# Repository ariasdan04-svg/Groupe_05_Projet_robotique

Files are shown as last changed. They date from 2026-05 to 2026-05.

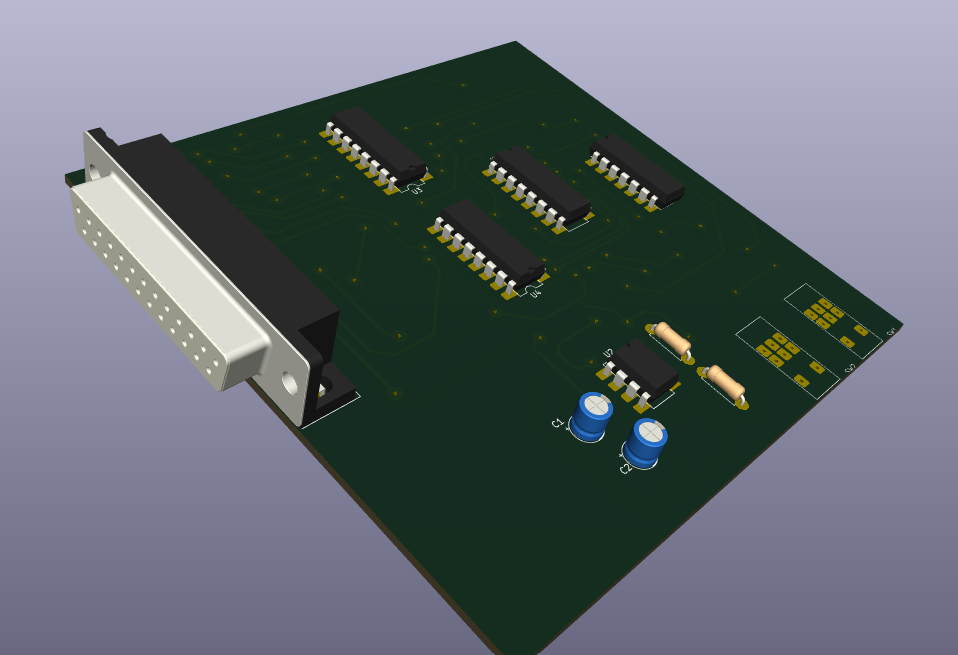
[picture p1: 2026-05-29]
Capture d’écran 2026-05-24 181659.png

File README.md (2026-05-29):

rojectile via catapulte.
# Projet Robotique – Groupe 05
**Université Évry Paris-Saclay – L3 – 2025-2026**

## Équipe
| Nom | Rôle |
|-----|---|
| Dan-Arias KALEMA MASUDI | Chef de projet / Code FSM |
| Ndoumbe DIAKHOUMPA | Responsable matériel et passerel |
| Karim Zerdali | Responsable de la gestion global du programme|
|Adame Gun Nouni| Responsable Structure,Design coque |
|David Papagiorgou | Responsable plan d'experience|
|Ines MELAB | Responsable Chrono et Capteur|
|Kevin RAZAFINDRATSIORY | Responsable Chrono|

## Description du robot
Robot autonome 3 roues sur base Arduino Uno (kit Makeblock).  
Il suit une ligne noire, évite des obstacles, détecte des couleurs et lance un p
**Matériel :** DRV8830 I2C, capteur ligne Me RGB (0x20), ultrason Grove D4, servo D3, NeoPixel 30 LEDs, TCS34725, LCD Grove 16×2 I2C.

## FSM – 8 états
| État | Rôle |
|---|---|
| `SUIVI_LIGNE` | Suivi de la ligne noire |
| `TUNNEL` | Traversée sans capteur ligne |
| `EVITEMENT_O1` | Contournement gauche |
| `EVITEMENT_O2` | Contournement droit |
| `DETECTION_COULEUR` | Identification zone colorée |
| `DEMI_TOUR` | Demi-tour en bout de parcours |
| `REPRENDRE_LIGNE` | Réacquisition ligne après évitement |
| `ARRIVE` | Fin de parcours |

## Structure du dépôt
Groupe_05_Projet_robotique/
├── code/               # Code Arduino (FSM)
├── electronique/       # Schémas et PCB chronomètre
├── etude_analytique/   # Plans d’expérience et CSV
└── design_coque/       # Réflexions conception mécanique

## Règles de contribution
- Ne jamais travailler directement sur `main`
- Un commit = une modification claire avec message précis
- Chaque dossier contient un `README.md`
- Ne pas committer de fichiers binaires (.pdf, .docx, .stl…)
- Toute fusion passe par une **Pull Request** validée par le chef de projet

- ## Gestion globale du programme – Karim Zerdali

### Rôle
Conception et développement de l'ensemble de la logique de pilotage :
machine à états finis (FSM), suivi de ligne, tunnel, évitement obstacles,
détection couleur, LEDs NeoPixel, afficheur LCD et tir catapulte.

### Fichiers
| Fichier | Description |
|---|---|
| `code/robot_final/robot_final.ino` | Code global complet — FSM 8 états |
| `code/tests/Ultrason_ino.ino` | Test unitaire capteur ultrason |
| `code/tests/suiveur_ligne_V2.ino` | Test capteur ligne (version préliminaire) |
| `code/tests/test_tunel_obs_ino.ino` | Test tunnel + évitement obstacles |
| `code/tests/test_parcour_led_ino.ino` | Test parcours complet + LEDs + couleur |

### Dépendances
- `Wire.h` — communication I2C
- `Servo.h` — pilotage servo ultrason
- `Adafruit_TCS34725` — capteur couleur
- `Adafruit_NeoPixel` — LEDs RGB
- `rgb_lcd` — afficheur LCD Grove

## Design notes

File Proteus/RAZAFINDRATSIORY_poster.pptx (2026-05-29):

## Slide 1

Circuit De Chronométrage
RAZAFINDRATSIORY, KEVIN – EATI – Groupe 5

2. Conception et modélisation

3. Développements et mise en œuvre

4. Etat d’avancement et/ou Résultat

À ce stade, le système fonctionne correctement sur le circuit de démonstration: l’horloge, le comptage et l’affichage sont fonctionnels. En revanche, l’intégration sur le circuit du concours n’est pas encore fonctionnelle, en raison de différences de câblage et de contraintes supplémentaires qui nécessitent des ajustements.

Mots-clés

Chronométrage

- Oscillateur NE555
- Compteur CD4518
- Décodage CD4511
- Affichage 7 segments

Conception électronique

- Propeus
- Kicad
- Typon

Bascule D utilisée pour stocker un bit et contrôler la logique du chronomètre

CD4013

Barrière

Switch

CD4511 convertit le code BCD provenant du compteur en signaux adaptés aux sept segments de l’afficheur. Il assure l’allumage correct des segments pour afficher les chiffres de 0 à 9

CD4511

1.Objectifs et spécifications

Réaliser un système de chronométrage, capable de mesurer le temps et de l’afficher sur un afficheur 7 segments, en utilisant uniquement des composants simples (sans microcontrôleur)

Le CD4518 reçoit les impulsions d’horloge et incrémente un comptage en code BCD. Il fournit quatre sorties logiques (Q0–Q3) représentant la valeur numérique du temps mesuré. Un signal de reset permet de remettre le compteur à zéro.

CD418

NE555

Génère un signal périodique stable qui cadence le comptage.

Afficheur 7 segments

Reçoit les signaux du décodeur et affiche la valeur du chronomètre

- Test sur un Labdec

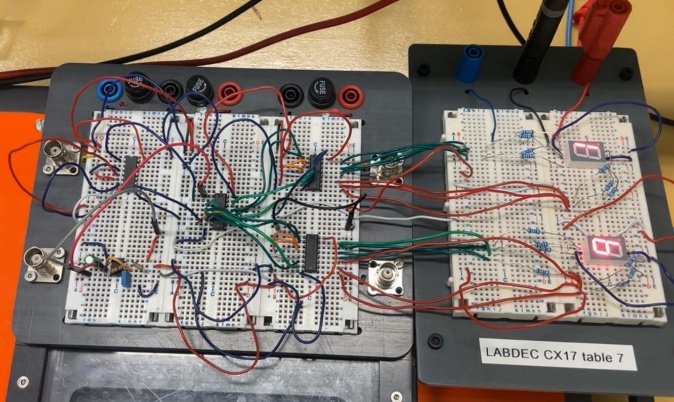
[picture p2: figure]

- Simulation sur Proteus

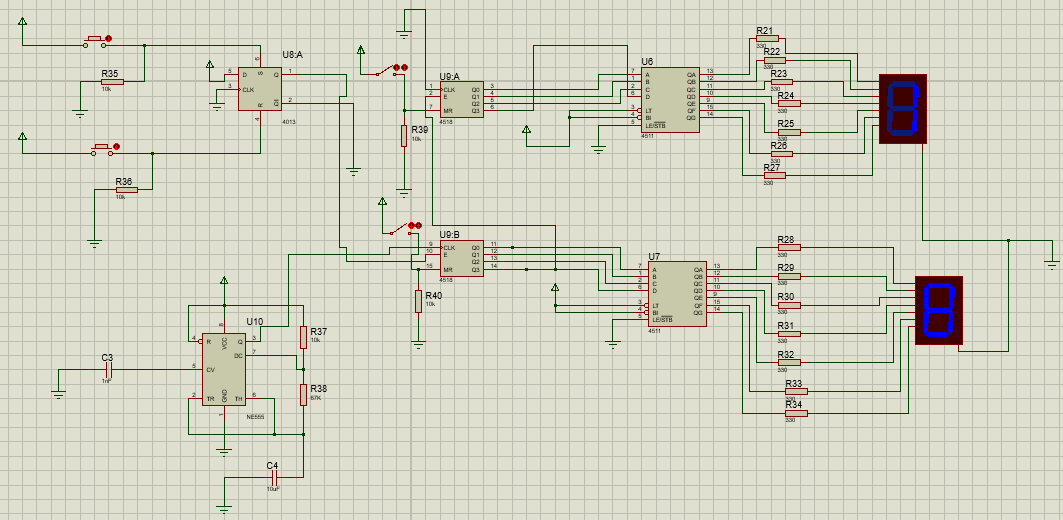
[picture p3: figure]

- la carte sur Kitcad

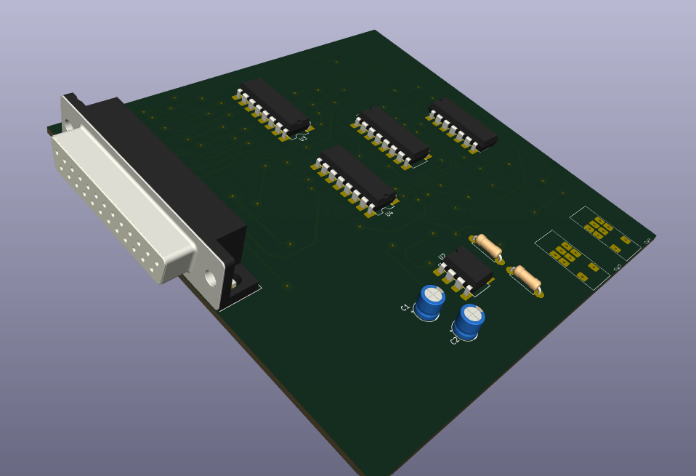
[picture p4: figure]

- Perçage et soudage

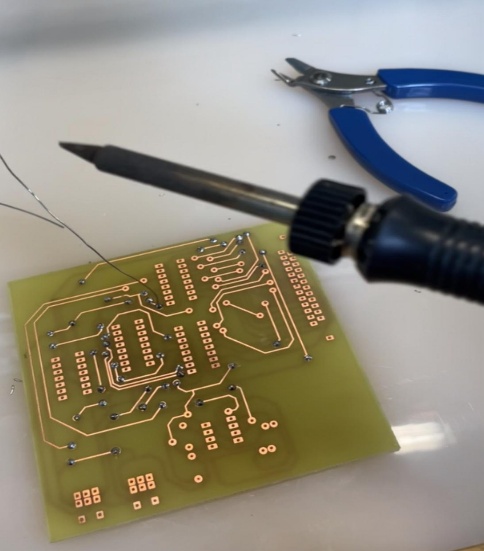
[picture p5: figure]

- Imprimer la carte

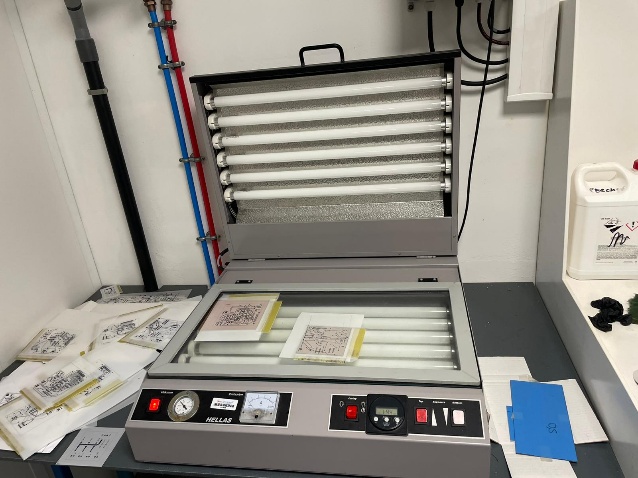
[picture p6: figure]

- Correction des problèmes

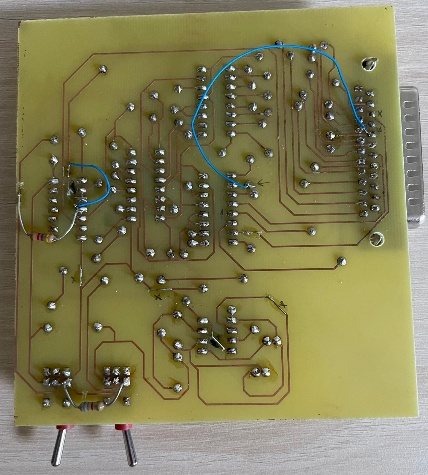
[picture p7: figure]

Compétences acquises

- Travail en équipe
- Découvert de Proteus
- Utilisation de Kicad
- Routage sous Kicad
- Perçage et soudage

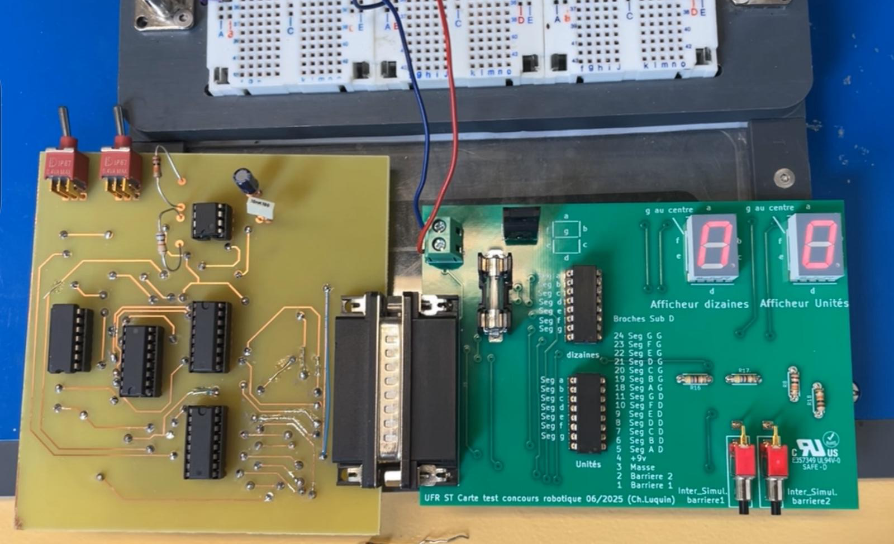
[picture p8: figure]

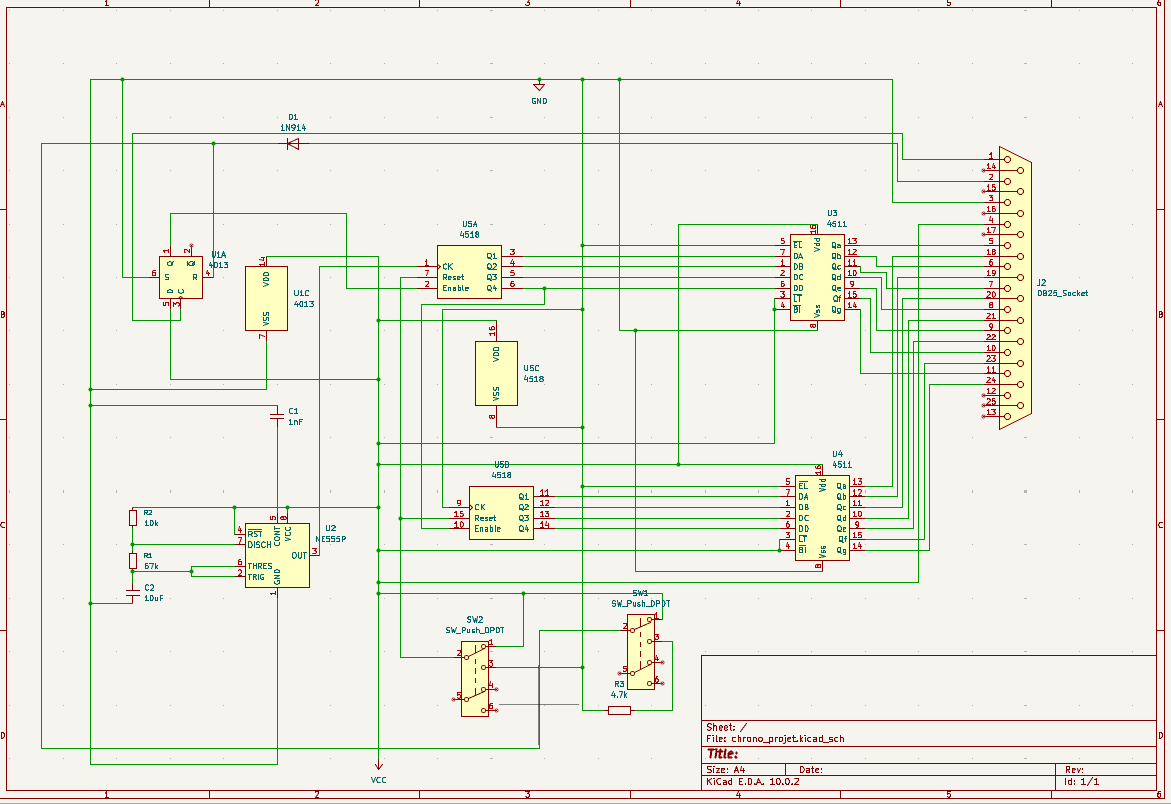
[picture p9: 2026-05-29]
Capture d’écran 2026-05-27 003153.png

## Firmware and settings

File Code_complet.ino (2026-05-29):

#include <Wire.h>
#include <Servo.h>
#include <Adafruit_TCS34725.h>
#include <Adafruit_NeoPixel.h>
#include "rgb_lcd.h"

#define PIN_SERVO     3
#define PIN_ULTRASON  4

#define MOTEUR_G     0x66
#define MOTEUR_D     0x68
#define MOTEUR_CA    0x60
#define ADDR_LF      0x20

#define AVANT    0x01
#define ARRIERE  0x02
#define FREIN    0x03
#define REG_DIGITAL 0x07

#define SERVO_AVANT   90    // centre physique
#define SERVO_GAUCHE  0     // gauche = 0°
#define SERVO_DROITE  180   // droite = 180°
#define SERVO_TUNNEL   30   // 30° droite pour détection tunnel

#define VITESSE_BASE   42
#define VITESSE_LENTE  42
#define VITESSE_PIVOT  44
#define VITESSE_TUNNEL 30
#define KP             0.0025
#define ZONE_MORTE     3000
#define TRIM_G         -5
#define TRIM_D         0

#define DIST_URGENCE       2
#define DIST_OBSTACLE      25
#define DIST_INFINIE       9999
#define SEUIL_LIGNE_PERDUE 20

#define SEUIL_ARRIVEE      30
#define DUREE_TOURNE_90    820
#define DUREE_TOURNE_90_G  920
#define DUREE_TOURNE_80    730
#define DUREE_TOURNE_70    650
#define DUREE_PAR_CM       35
#define DIST_RECUL_INIT    8
#define SEUIL_OBSTACLE_COTE  70
#define DIST_DEPASSEMENT     25
#define DIST_ECART           55
#define DIST_ECART2        3200
#define DIST_APPROCHE        35
#define TUNNEL_TIMEOUT     25000UL

#define PIN_LED          6
#define NUMPIXELS        30
#define DIST_MUR         5
#define RECUL_MS         1400
#define DEMI_TOUR_MS     2200
#define VITESSE_MONTEE   55
#define DELAI_TIR_MS     5000


enum Etat { SUIVI_LIGNE, TUNNEL, EVITEMENT_O1, EVITEMENT_O2, DETECTION_COULEUR, DEMI_TOUR, REPRENDRE_LIGNE, ARRIVE };

Etat     etatRobot           = SUIVI_LIGNE;
uint8_t  compteurArrivee     = 0;
uint16_t compteurLignePerdue = 0;
uint8_t  nbObstaclesEvites   = 0;
bool     apresObstacle       = false;
bool     tunnelTraverse      = false;

Servo    servoUs;
int      servoPos            = SERVO_AVANT;
unsigned long tunnelExitTime = 0;

Adafruit_NeoPixel strip(NUMPIXELS, PIN_LED, NEO_RGB + NEO_KHZ800);
Adafruit_TCS34725 tcs = Adafruit_TCS34725(TCS34725_INTEGRATIONTIME_50MS, TCS34725_GAIN_4X);
bool apresDetectionCouleur = false;

rgb_lcd lcd;
long          distTunnel  = 0;
int           posLigne    = 0;
char          nomCouleur[17] = "";
unsigned long tLcd        = 0;

void majLcd() {
  char buf[17];
  lcd.setCursor(0, 0);
  switch (etatRobot) {
    case SUIVI_LIGNE:       lcd.print("SUIVI LIGNE     "); break;
    case TUNNEL:            lcd.print("TUNNEL          "); break;
    case EVITEMENT_O1:      lcd.print("OBSTACLE 1      "); break;
    case EVITEMENT_O2:      lcd.print("OBSTACLE 2      "); break;
    case DETECTION_COULEUR: lcd.print("DETECTION       "); break;
    case DEMI_TOUR:         lcd.print("DEMI-TOUR       "); break;
    case REPRENDRE_LIGNE:   lcd.print("CHERCHE LIGNE   "); break;
    case ARRIVE:            lcd.print("*** ARRIVE! *** "); break;
  }
  lcd.setCursor(0, 1);
  switch (etatRobot) {
    case SUIVI_LIGNE:
      if      (posLigne >= 20000)  snprintf(buf, 17, "VIRAGE DROITE   ");
      else if (posLigne <= -20000) snprintf(buf, 17, "VIRAGE GAUCHE   ");
      else                         snprintf(buf, 17, "LIGNE DROITE    ");
      lcd.print(buf); break;
    case TUNNEL:
      snprintf(buf, 17, "Mur: %3dcm      ", (int)distTunnel);
      lcd.print(buf); break;
    case EVITEMENT_O1:
    case EVITEMENT_O2:
      lcd.print("Longement...    "); break;
    case DETECTION_COULEUR:
    case DEMI_TOUR:
      snprintf(buf, 17, "%-16s", nomCouleur);
      lcd.print(buf); break;
    default:
      lcd.print("                "); break;
  }
}

void piloterMoteur(byte adresse, byte direction, byte vitesse) {
  vitesse = constrain(vitesse, 0, 63);
  Wire.beginTransmission(adresse);
  Wire.write(0x00);
  Wire.write((vitesse << 2) | direction);
  Wire.endTransmission();
}

void avancer(int vG, int vD) {
  vG = constrain(vG + TRIM_G, 0, 63);
  vD = constrain(vD + TRIM_D, 0, 63);
  piloterMoteur(MOTEUR_G, AVANT,   vG);
  piloterMoteur(MOTEUR_D, ARRIERE, vD);
}

void arreter() {
  piloterMoteur(MOTEUR_G, FREIN, 0);
  piloterMoteur(MOTEUR_D, FREIN, 0);
}

void servoEcrire(int angle) {
  servoPos = angle;
  servoUs.writeMicroseconds(map(angle, 0, 180, 500, 2500));
}

void tournerGauche(unsigned long duree) {
  piloterMoteur(MOTEUR_G, ARRIERE, VITESSE_PIVOT);
  piloterMoteur(MOTEUR_D, ARRIERE, VITESSE_PIVOT);
  delay(duree);
  arreter(); delay(50);
}

void tournerDroite(unsigned long duree) {
  piloterMoteur(MOTEUR_G, AVANT,   VITESSE_PIVOT);
  piloterMoteur(MOTEUR_D, AVANT,   VITESSE_PIVOT);
  delay(duree);
  arreter(); delay(50);
}

void reculer(int vitesse, unsigned long duree) {
  piloterMoteur(MOTEUR_G, ARRIERE, vitesse);
  piloterMoteur(MOTEUR_D, AVANT,   vitesse);
  delay(duree);
  arreter(); delay(50);
}

void avancerDroit(int vitesse, unsigned long duree) {
  avancer(vitesse, vitesse);
  delay(duree);
  arreter(); delay(300);
}

long mesureUltrason() {
  pinMode(PIN_ULTRASON, OUTPUT);
  digitalWrite(PIN_ULTRASON, LOW);  delayMicroseconds(2);
  digitalWrite(PIN_ULTRASON, HIGH); delayMicroseconds(10);
  digitalWrite(PIN_ULTRASON, LOW);
  pinMode(PIN_ULTRASON, INPUT);
  long d = pulseIn(PIN_ULTRASON, HIGH, 15000UL);
  return (d == 0) ? DIST_INFINIE : d / 58;
}

void verifierUltrason() {
  long dist = mesureUltrason();
  if (dist > 0 && dist <= DIST_URGENCE) {
    arreter();
    while (mesureUltrason() <= DIST_URGENCE) delay(50);
  }
}

int lirePosition() {
  Wire.beginTransmission(ADDR_LF);
  Wire.write(REG_DIGITAL);
  Wire.endTransmission(false);
  Wire.requestFrom((uint8_t)ADDR_LF, (uint8_t)1);
  if (!Wire.available()) return 0;
  uint8_t brut = Wire.read();
  uint8_t etat = (~brut) & 0x0F;

  switch (etat) {
    case 0b1001:
    case 0b0110: return 1000;
    case 0b1000:
    case 0b1100: return -20000;
    case 0b0001:
    case 0b0011: return 20000;
    case 0b1110: return -30000;
    case 0b0111: return 30000;
    case 0b1111: return 0;
    case 0b0000: return -1;
    default:     return 1000;
  }
}

bool chercherLigne(unsigned long timeoutMs) {
  avancer(VITESSE_LENTE, VITESSE_LENTE);
  unsigned long debut = millis();
  while (millis() - debut < timeoutMs) {
    int pos = lirePosition();
    if (pos != -1) { arreter(); delay(50); return true; }
    delay(15);
  }
  arreter();
  return false;
}

void suivreLigneImmediatement(unsigned long dureeMs) {
  uint8_t cNoir = 0;
  unsigned long t = millis();
  while (millis() - t < dureeMs) {
    int p = lirePosition();
    if (p == -1) {
      if (++cNoir >= 30) break;
      avancer(VITESSE_BASE, VITESSE_BASE);
    } else {
      cNoir = 0;
      int corr = (p != 0 && abs(p) >= ZONE_MORTE) ? (int)(KP * p) : 0;
      avancer(VITESSE_BASE - corr, VITESSE_BASE + corr);
    }
    delay(5);
  }
}
void setup() {
  Wire.begin();
  Serial.begin(9600);
  servoUs.attach(PIN_SERVO);
  servoEcrire(SERVO_AVANT);
  strip.begin();
  strip.show();
  tcs.begin();
  lcd.begin(16, 2);
  lcd.setRGB(0, 128, 255);
  lcd.setCursor(0, 0); lcd.print("  ROBOT PRET    ");
  lcd.setCursor(0, 1); lcd.print("      GO !      ");
  delay(500);
  arreter();
  Serial.println("GO");
}

void loop() {
  verifierUltrason();

  if (millis() - tLcd > 400) { tLcd = millis(); majLcd(); }

  switch (etatRobot) {
    case SUIVI_LIGNE:       gererSuiviLigne();   break;
    case TUNNEL:            gererTunnel();       break;
    case EVITEMENT_O1:      evitementDroite();   break;
    case EVITEMENT_O2:      evitementGauche();   break;
    case DETECTION_COULEUR: gererCouleur();      break;
    case DEMI_TOUR:         gererDemiTour();     break;
    case REPRENDRE_LIGNE:   gererRepriseLigne(); break;
    case ARRIVE:
      piloterMoteur(MOTEUR_CA, AVANT, 45);
      arreter();
      delay(500);
      break;
  }
}

void gererSuiviLigne() {
  int position = lirePosition();

  if (apresObstacle && position != -1) {
    apresObstacle = false;
    compteurArrivee = 0;
  }

  if (position != 0 && position != -1) {
    compteurLignePerdue = 0;
    if (servoPos != SERVO_AVANT) servoEcrire(SERVO_AVANT);
  } else {
    compteurLignePerdue++;
  }

  if (compteurLignePerdue > SEUIL_LIGNE_PERDUE && !tunnelTraverse && millis() - tunnelExitTime > 2000UL) {
    etatRobot = TUNNEL;
    compteurLignePerdue = 0;
    compteurArrivee = 0;
    Serial.println("-> TUNNEL");
    return;
  }

  if (position == -1) {
    if (apresObstacle) {
      apresObstacle = false;
      compteurArrivee = 0;
      return;
    }
    compteurArrivee++;
    if (compteurArrivee >= SEUIL_ARRIVEE && millis() - tunnelExitTime > 2000UL) {
      Serial.println("*** ARRIVEE ***");
      arreter();
      lcd.setCursor(0, 0); lcd.print("*** ARRIVEE ***  ");
      lcd.setCursor(0, 1); lcd.print("Chargez balle!  ");
      Serial.println("STOP ARRIVEE");
      delay(DELAI_TIR_MS);
      lcd.setCursor(0, 1); lcd.print("    TIR !       ");
      etatRobot = ARRIVE;
      return;
    }
    avancer(VITESSE_BASE, VITESSE_BASE);
    delay(5);
    return;
  }
  compteurArrivee = 0;

  if (servoPos == SERVO_AVANT) {
    long distAvant = mesureUltrason();
    if (nbObstaclesEvites >= 2 && !apresDetectionCouleur) {
      if (distAvant <= DIST_MUR && distAvant > 0) {
        arreter(); delay(200);
        etatRobot = DETECTION_COULEUR;
        return;
      }
    } else if (!apresDetectionCouleur && nbObstaclesEvites < 2) {
      if (distAvant < DIST_OBSTACLE && millis() - tunnelExitTime > 1500UL) {
        arreter(); delay(200);
        etatRobot = (nbObstaclesEvites == 0) ? EVITEMENT_O1 : EVITEMENT_O2;
        compteurArrivee = 0;
        return;
      }
    }
  }

  if (position == 0) {
    avancer(VITESSE_BASE, VITESSE_BASE);
    return;
  }

  posLigne = position;
  int correction = (int)(KP * position);
  if (abs(position) < ZONE_MORTE) {
    avancer(VITESSE_BASE, VITESSE_BASE);
  } else {
    avancer(VITESSE_BASE - correction, VITESSE_BASE + correction);
  }
}

void gererTunnel() {
  unsigned long debut = millis();
  const long CIBLE_G  = 30;
  const int  MAX_CORR = 12;

  servoEcrire(SERVO_TUNNEL);
  delay(150);

  while (millis() - debut < TUNNEL_TIMEOUT) {

    int pos = lirePosition();
    if (pos != -1) {
      servoEcrire(SERVO_AVANT);
      delay(150);
      suivreLigneImmediatement(1500UL);
      tunnelTraverse = true;
      tunnelExitTime = millis();
      etatRobot = SUIVI_LIGNE;
      compteurLignePerdue = 0;
      compteurArrivee = 0;
      return;
    }

    long distG = mesureUltrason();
    distTunnel = distG;
    if (millis() - tLcd > 400) { tLcd = millis(); majLcd(); }
    Serial.print("G:"); Serial.println(distG);

    if (distG > 0 && distG < 80) {
      int correction = constrain((int)((distG - CIBLE_G) * 4 / 5), -MAX_CORR, MAX_CORR);
      avancer(VITESSE_TUNNEL - correction, VITESSE_TUNNEL + correction);
    } else {
      avancer(VITESSE_TUNNEL, VITESSE_TUNNEL);
    }

    delay(30);
  }

  servoEcrire(SERVO_AVANT);
  tunnelExitTime = millis();
  etatRobot = SUIVI_LIGNE;
  compteurLignePerdue = 0;
  compteurArrivee = 0;
}

void longerObstacleParDroite() {
  unsigned long debut = millis();
  bool obstacleVu = false;
  unsigned long tempsObstaclePerdu = 0;

  while (millis() - debut < 20000UL) {
    long d = mesureUltrason();
    Serial.print(F("D:")); Serial.println(d);

    if (!obstacleVu) {
      if (d < 30 && d > 5) {
        obstacleVu = true;
      } else {
        avancer(VITESSE_LENTE, VITESSE_LENTE);
        if (millis() - debut > 3000UL) { arreter(); delay(50); return; }
      }
      delay(50); continue;
    }

    if (d > 30 || d == DIST_INFINIE) {
      if (tempsObstaclePerdu == 0) tempsObstaclePerdu = millis();
      if (millis() - tempsObstaclePerdu > 250) { arreter(); delay(50); return; }
      avancer(VITESSE_LENTE, VITESSE_LENTE);
    } else {
      tempsObstaclePerdu = 0;
      long err = d - 15;
      if (abs(err) < 5)   avancer(VITESSE_LENTE,     VITESSE_LENTE);
      else if (err > 0)   avancer(VITESSE_LENTE + 8, VITESSE_LENTE - 8);  // trop loin → virer droite vers obstacle
      else                avancer(VITESSE_LENTE - 8, VITESSE_LENTE + 8);  // trop proche → virer gauche
    }
    delay(50);
  }
  arreter(); delay(50);
}

void longerObstacleParGauche() {
  unsigned long debut = millis();
  bool obstacleVu = false;
  unsigned long tempsObstaclePerdu = 0;

  while (millis() - debut < 20000UL) {
    long d = mesureUltrason();
    Serial.print(F("G:")); Serial.println(d);

    if (!obstacleVu) {
      if (d < 60 && d > 5) {
        obstacleVu = true;
      } else {
        avancer(VITESSE_LENTE, VITESSE_LENTE);
        if (millis() - debut > 3000UL) { arreter(); delay(50); return; }
      }
      delay(50); continue;
    }

    if (d > 60 || d == DIST_INFINIE) {
      if (tempsObstaclePerdu == 0) tempsObstaclePerdu = millis();
      if (millis() - tempsObstaclePerdu > 100) { arreter(); delay(50); return; }
      avancer(VITESSE_LENTE, VITESSE_LENTE);
    } else {
      tempsObstaclePerdu = 0;
      long err = d - 30;
      if (abs(err) < 5)   avancer(VITESSE_LENTE,     VITESSE_LENTE);
      else if (err > 0)   avancer(VITESSE_LENTE - 8, VITESSE_LENTE + 8);
      else                avancer(VITESSE_LENTE + 8, VITESSE_LENTE - 8);
    }
    delay(50);
  }
  arreter(); delay(50);
}

void evitementGauche() {
  Serial.println(F("=== O1 GAUCHE ==="));
  majLcd();
  servoEcrire(SERVO_AVANT); delay(200);
  reculer(VITESSE_LENTE, DIST_RECUL_INIT * DUREE_PAR_CM);

  Serial.println(F("pivot G"));
  tournerGauche(DUREE_TOURNE_90_G);
  avancerDroit(VITESSE_LENTE, DIST_ECART2);

  Serial.println(F("pivot D + longer"));
  tournerDroite(DUREE_TOURNE_90);
  servoEcrire(SERVO_DROITE); delay(400);
  longerObstacleParDroite();

  Serial.println(F("retour"));
  servoEcrire(SERVO_AVANT); delay(200);
  tournerDroite(DUREE_TOURNE_80);

  Serial.println(F("cherche ligne"));
  tunnelExitTime = millis();
  chercherLigne(5000UL);
  suivreLigneImmediatement(1500UL);

  apresObstacle = true;
  nbObstaclesEvites++;
  etatRobot = SUIVI_LIGNE;
  compteurLignePerdue = 0;
  tunnelExitTime = millis();
}

void evitementDroite() {
  Serial.println(F("=== O1 DROITE ==="));
  majLcd();
  servoEcrire(SERVO_AVANT); delay(200);
  reculer(VITESSE_LENTE, DIST_RECUL_INIT * DUREE_PAR_CM);

  Serial.println(F("pivot D"));
  tournerDroite(DUREE_TOURNE_90);
  avancerDroit(VITESSE_LENTE, DIST_ECART * DUREE_PAR_CM);

  Serial.println(F("pivot G + longer"));
  tournerGauche(DUREE_TOURNE_90);
  servoEcrire(SERVO_GAUCHE); delay(400);
  longerObstacleParGauche();

  Serial.println(F("retour"));
  servoEcrire(SERVO_AVANT); delay(200);
  tournerGauche(DUREE_TOURNE_90_G);

  Serial.println(F("cherche ligne"));
  tunnelExitTime = millis();
  chercherLigne(5000UL);
  suivreLigneImmediatement(1500UL);

  apresObstacle = true;
  nbObstaclesEvites++;
  etatRobot = SUIVI_LIGNE;
  compteurLignePerdue = 0;
  tunnelExitTime = millis();
}

void allumerLED(uint8_t r, uint8_t g, uint8_t b) {
  for (int i = 0; i < NUMPIXELS; i++)
    strip.setPixelColor(i, strip.Color(r, g, b));
  strip.show();
}

void gererCouleur() {
  Serial.println(F("-> COULEUR"));
  uint16_t r, g, b, c;
  tcs.getRawData(&r, &g, &b, &c);
  Serial.print("R:"); Serial.print(r);
  Serial.print(" G:"); Serial.print(g);
  Serial.print(" B:"); Serial.println(b);

  uint8_t ledR = 0, ledG = 0, ledB = 0;
  if      (r > g && r > b) { ledR = 255;                         strncpy(nomCouleur, "ROUGE           ", 17); Serial.println(F("ROUGE")); }
  else if (g > r && g > b) { ledG = 255;                         strncpy(nomCouleur, "VERT            ", 17); Serial.println(F("VERT"));  }
  else if (b > r && b > g) { ledB = 255;                         strncpy(nomCouleur, "BLEU            ", 17); Serial.println(F("BLEU"));  }
  else                     { ledR = 255; ledG = 255; ledB = 255; strncpy(nomCouleur, "BLANC           ", 17); Serial.println(F("BLANC")); }
  majLcd();

  for (int i = 0; i < 3; i++) {
    allumerLED(ledR, ledG, ledB); delay(500);
    allumerLED(0, 0, 0);          delay(500);
  }

  apresDetectionCouleur = true;
  etatRobot = DEMI_TOUR;
}

void gererDemiTour() {
  Serial.println(F("-> DEMI-TOUR"));
  majLcd();
  reculer(VITESSE_MONTEE, RECUL_MS);
  piloterMoteur(MOTEUR_G, ARRIERE, VITESSE_MONTEE);
  piloterMoteur(MOTEUR_D, ARRIERE, VITESSE_MONTEE);
  delay(DEMI_TOUR_MS);
  arreter(); delay(50);
  tunnelExitTime = millis();
  etatRobot = REPRENDRE_LIGNE;
}

void gererRepriseLigne() {
  int position = lirePosition();
  if (position != -1) {
    Serial.println(F("-> LIGNE"));
    arreter(); delay(100);
    suivreLigneImmediatement(1000UL);
    tunnelExitTime = millis();
    compteurLignePerdue = 0;
    compteurArrivee = 0;
    etatRobot = SUIVI_LIGNE;
    return;
  }
  avancer(VITESSE_MONTEE, VITESSE_MONTEE);
  delay(5);
}

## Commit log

2026-05-29 Add files via upload
    Empreinte des deux switchs
2026-05-29 Add files via upload
    Partie Kicad
    [chrono_projet - Copie.kicad_pcb, chrono_projet.kicad_pcb, chrono_projet.kicad_sch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]
2026-05-29 Add files via upload
    Parttie Kicad: modification Kicad à faire
